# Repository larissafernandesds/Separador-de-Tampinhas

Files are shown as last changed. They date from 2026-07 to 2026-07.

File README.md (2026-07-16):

<h1 align="center">♻️ Separador de Tampinhas ♻️</h1>
<h3 align="center">Grupo 4</h3>

<div align="center">



  





</div>

---

## 📝 Descrição do Projeto  

O **Grupo 4** desenvolveu um **Separador Automático de Tampinhas de Garrafa PET por Cor**. O protótipo possui um **mecanismo alimentador**, no qual o usuário deposita várias tampinhas. Esse mecanismo organiza e **enfileira as tampinhas**, permitindo que elas passem pelo sensor de cores, garantindo uma leitura precisa. Após a leitura, o **Arduino Uno** processa os valores obtidos pelo sensor, identifica a cor da tampinha por meio de perfis previamente calibrados e aciona **servomotores**, responsáveis por direcioná-la ao compartimento correspondente. O sistema também conta com um **display LCD** com módulo I2C, utilizado para fornecer e coletar informações ao usuário durante a calibração.  

---  

## 🎯 Objetivo  

Desenvolver um sistema automatizado capaz de identificar e classificar tampinhas plásticas por cor, aplicando conceitos de sistemas embarcados, eletrônica, automação e programação para tornar o processo de separação mais eficiente e preciso.

---

## 💡 Motivação

A separação de tampinhas plásticas por cor é uma etapa importante do processo de reciclagem, pois aumenta a qualidade do material reciclado e facilita seu reaproveitamento. Quando diferentes cores são misturadas, o material obtido geralmente apresenta menor valor comercial e uma cor escura, dificultando sua reutilização em novos produtos.

Apesar de sua importância, esse processo ainda é realizado manualmente por diversas organizações, cooperativas e iniciativas sociais, tornando a atividade repetitiva, lenta e suscetível a erros. Além disso, a separação manual exige esforço físico constante e limita a quantidade de material que pode ser processada diariamente.

Além do benefício ambiental, a arrecadação de tampinhas possui um importante impacto social. Diversas **ONGs** utilizam a venda do material reciclável para financiar projetos beneficentes e ações de proteção ao meio ambiente. Entre elas destacam-se:

- **Tampinhas que Curam**: iniciativa que arrecada tampinhas plásticas para auxiliar no tratamento de crianças com câncer.
- **Ecopatas**: ONG que arrecada tampinhas plásticas e lacres de alumínio para contribuir com a preservação ambiental e o resgate de animais abandonados.
- **Tampinha do Bem**: projeto voltado à coleta e reciclagem de tampinhas, destinando os recursos obtidos para instituições sociais e ações de proteção animal.
- **Pontos de coleta**: como o instalado no Shopping Vitória (ES), que recebem tampinhas e lacres destinados posteriormente a projetos sociais e ambientais.

---

## 🌱 Impactos e ODSs

ODS

---

## ⚙️ Funcionamento Geral

O funcionamento ocorre em seis etapas principais:

1. O usuário deposita as tampinhas no compartimento superior.

2. O enfileirador organiza as tampinhas e libera apenas uma por vez.

3. A tampinha passa pelo sensor de cores, que realiza a leitura da sua cor.

4. O Arduino compara essa leitura com as cores previamente cadastradas.

5. O sistema identifica a cor correspondente.

6. Os servomotores direcionam a tampinha para o compartimento correto.
   
---

## 🛠️ Arquitetura do Sistema

O sistema foi dividido em dois subsistemas independentes, cada um executado por um Arduino Uno.

### * Enfileirador

O Enfileirador é responsável por organizar mecanicamente as tampinhas depositadas pelo usuário. Seu Arduino controla um servomotor que movimenta o mecanismo responsável por liberar a tampinhas no tubo de leitura.

### * Separador

Seu Arduino realiza a leitura do sensor de cor, identifica automaticamente a cor da tampinha, controla os servomotores responsáveis pelo direcionamento e gerencia toda a interface com o usuário através do display LCD e do encoder rotativo.

---

## 📁 Estrutura do Repositório

```text
Separador-de-Tampinhas/
├── Software/
│   ├── Enfileirador.ino
│   └── Separador.ino
│
├── Hardware/
│   ├── Modelos 3D/
│   └── Imagens/
│      
└── README.md
```
---

## 👶🏻 Como tudo começou...

<div align="center" style="display:flex; gap:20px;">
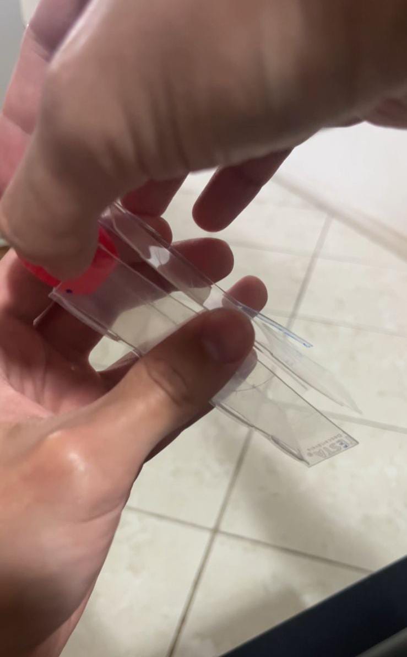
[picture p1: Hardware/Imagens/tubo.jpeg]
  
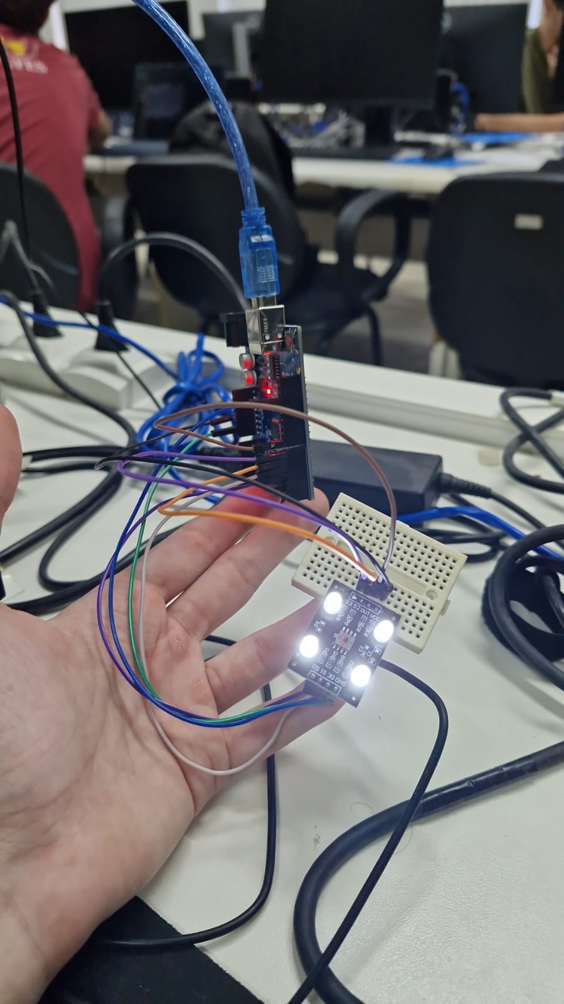
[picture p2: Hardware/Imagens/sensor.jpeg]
  
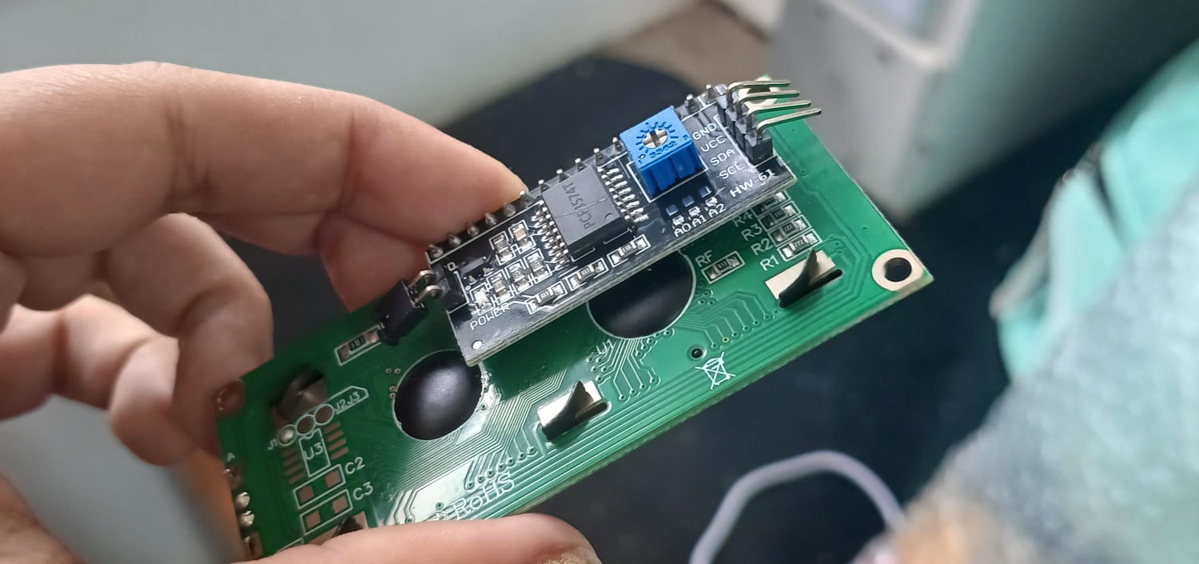
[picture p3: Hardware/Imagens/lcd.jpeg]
  
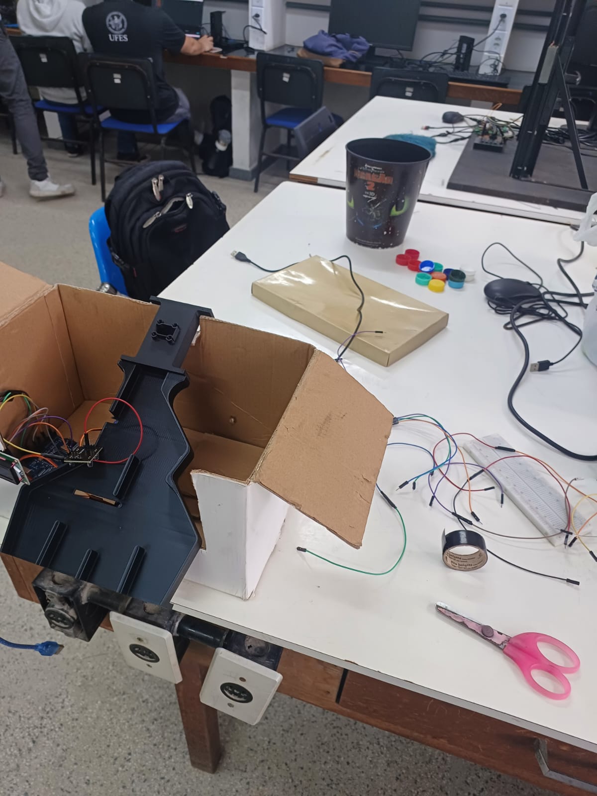
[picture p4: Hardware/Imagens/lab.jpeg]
  
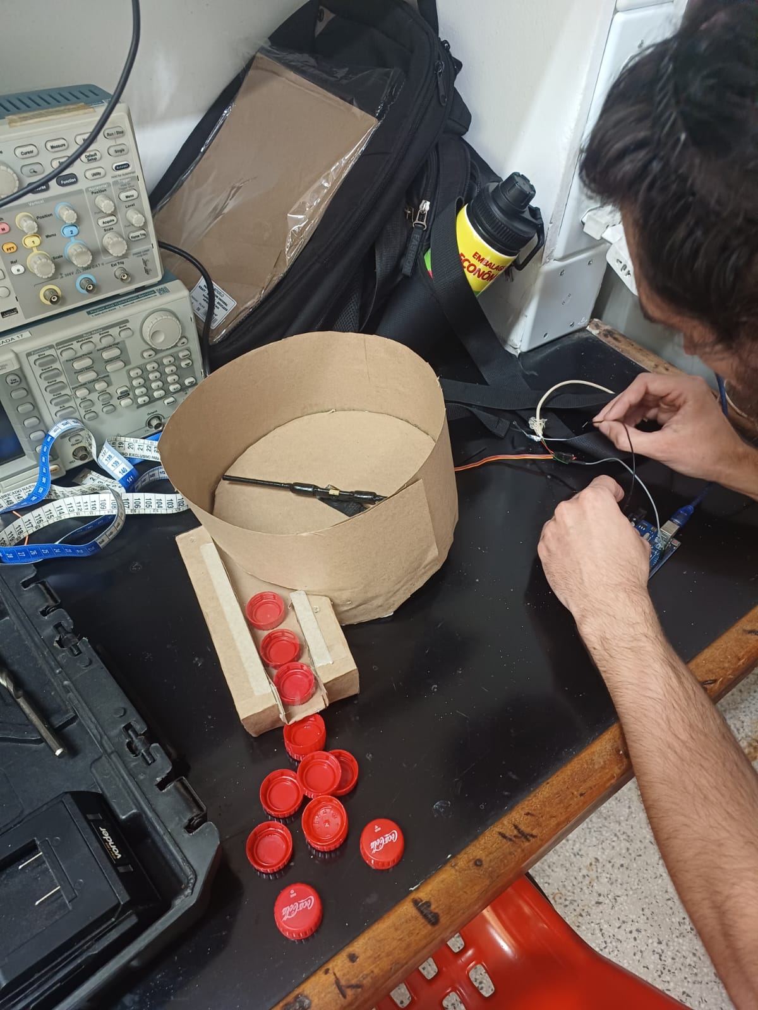
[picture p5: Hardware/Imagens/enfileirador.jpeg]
  
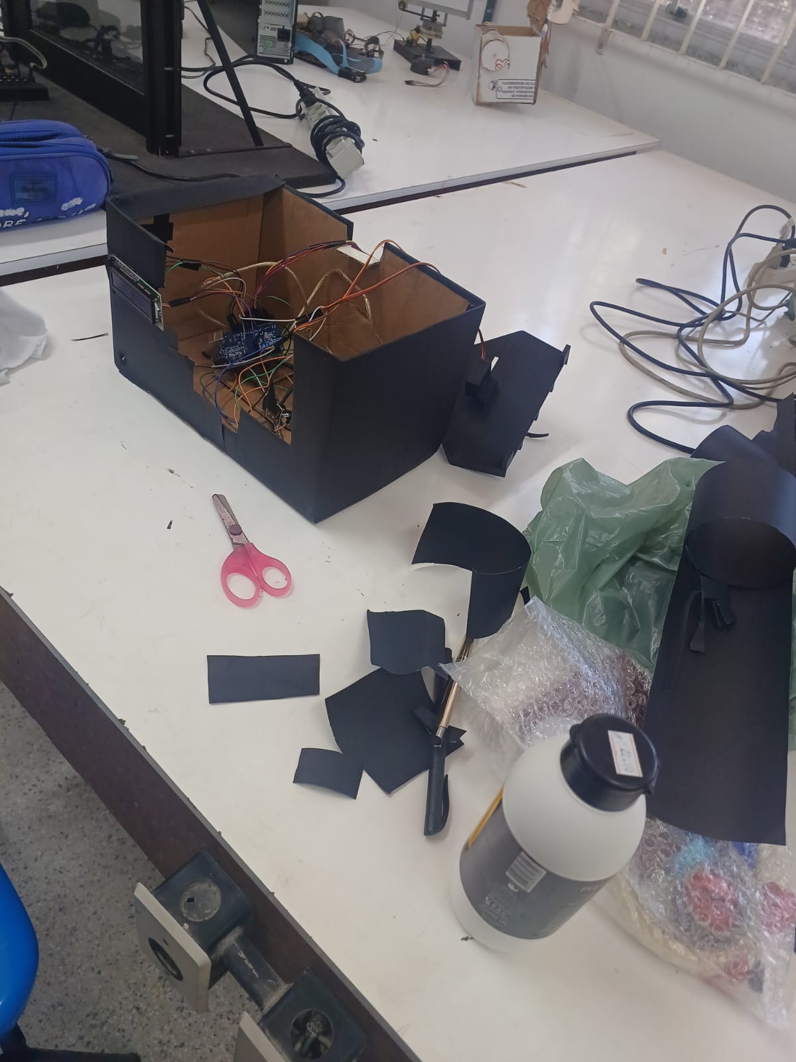
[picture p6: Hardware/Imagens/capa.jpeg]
 
</div>

---

## 📷 Imagens do Projeto Final

<div align="center" style="display:flex; gap:20px;">
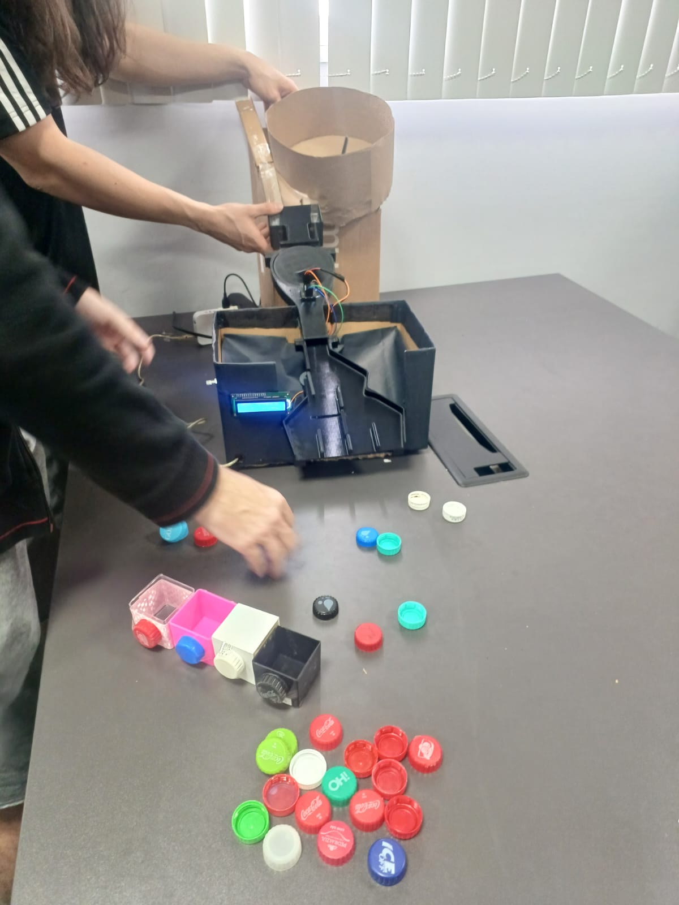
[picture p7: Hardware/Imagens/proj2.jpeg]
 
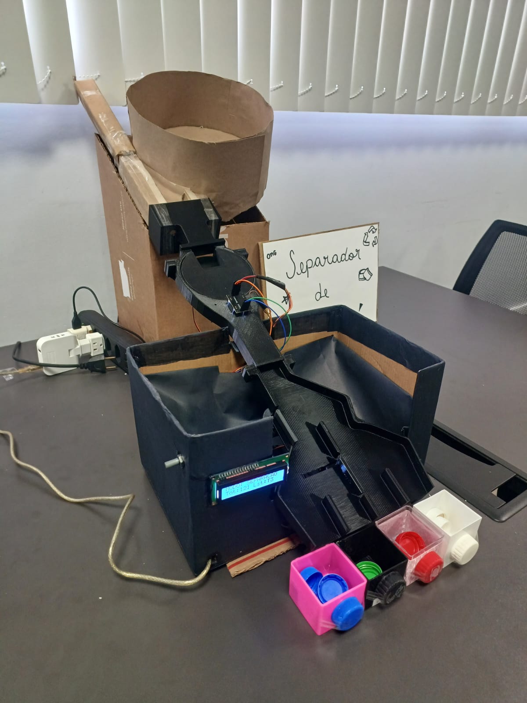
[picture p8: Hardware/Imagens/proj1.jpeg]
 
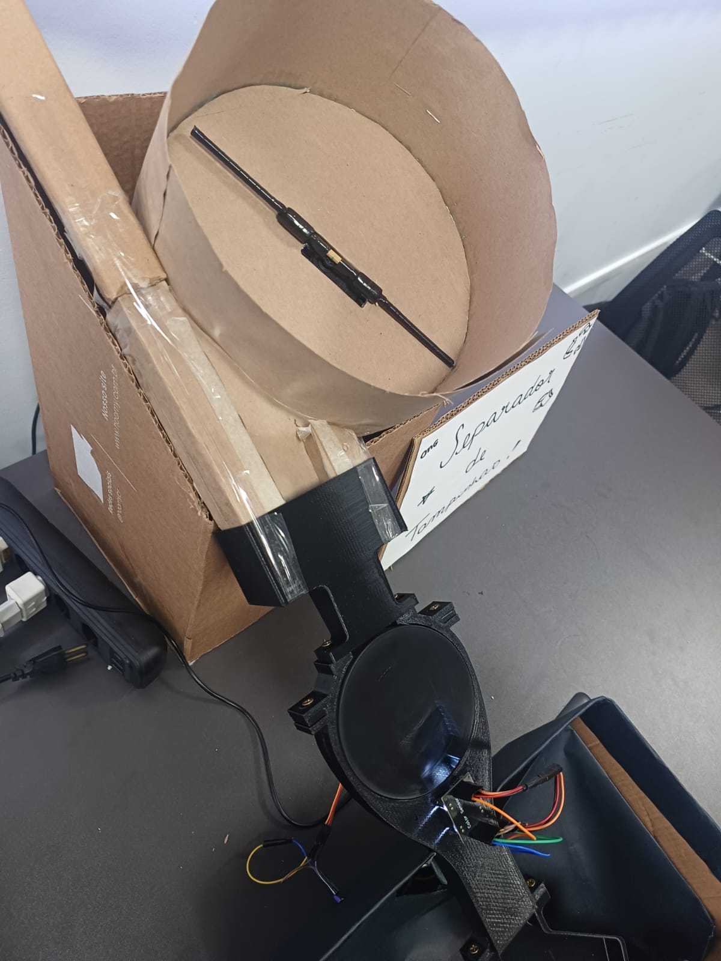
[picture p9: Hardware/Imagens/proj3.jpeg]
 
</div>

---

# 🧠 Software

O software do **Separador** foi desenvolvido utilizando uma máquina de estados composta por dois modos principais.

### Modo Operação

Neste modo o sistema permanece monitorando continuamente o sensor de cor.

Quando uma tampinha entra no tubo de leitura, o Arduino identifica essa alteração, realiza a leitura da cor e determina automaticamente qual compartimento deverá recebê-la.

Após a identificação, os servomotores são acionados e o display LCD atualiza as informações de operação.

### Modo Menu

Ao girar o encoder rotativo, o sistema entra automaticamente no modo de configuração.

Nesse modo o usuário pode:

- calibrar o tubo;
- calibrar cada tampinha;
- apagar toda a EEPROM.

Atualmente o sistema permite calibrar:

- **1 referência do tubo vazio** (utilizada para detectar a queda da tampinha);
- **3 perfis de cores distintos** (Tampa 1, Tampa 2 e Tampa 3).

Após alguns segundos sem interação, o sistema retorna automaticamente ao modo de operação.

---

## 🤖 Código do Separador

As principais funções do codigo do **Separador** (Separador.ino) são:

### setup()

Inicializa todos os periféricos do sistema, incluindo LCD, sensor de cores, encoder rotativo, servomotores e EEPROM.

Também realiza a leitura das calibrações armazenadas.

### loop()

Executa continuamente a máquina de estados do sistema.

Dependendo do modo atual, pode:

- monitorar o sensor de cores;
- controlar o menu;
- atualizar o display LCD;
- gerar os sinais PWM dos servomotores.

### lerRGB()

Seleciona sucessivamente os filtros vermelho, verde e azul do sensor de cor e realiza a leitura da frequência produzida pelo sensor.

### processarQueda()

Executa diversas leituras durante a passagem da tampinha, selecionando automaticamente a leitura mais representativa.

### identificarCor()

Compara a leitura atual com todos os perfis previamente calibrados e determina qual apresenta menor distância.

### moverServos()

Movimenta os servomotores para direcionar a tampinha ao compartimento correspondente.

### executarCalibracao()

Realiza o processo de calibração do tubo ou das tampinhas e armazena os dados na EEPROM.

### executarResetEEPROM()

Apaga todas as calibrações previamente armazenadas.

---

## 💻 Código do Enfileirador

O software do **Enfileirador** tem como única função controlar o servomotor responsável por organizar as tampinhas antes da etapa de identificação. Utilizando a biblioteca `Servo.h`, o programa alterna continuamente o sentido de rotação do servo por meio de comandos `servo.write()`, fazendo com que o mecanismo movimente as tampinhas e libere para o tubo de leitura. 

---

## 👥 Interface com o Usuário

Toda a interação entre o usuário e o sistema ocorre por meio de um display LCD 16×2 com comunicação I2C e de um encoder rotativo.

O display informa o estado atual do equipamento, auxilia durante o processo de calibração e apresenta mensagens de confirmação ao usuário.

Durante o funcionamento podem ser exibidas as seguintes telas.

### Tela de Inicialização

Logo após ligar o equipamento é apresentada uma tela de boas-vindas.

```text
SEPARADOR DE
TAMPINHAS
```
---

### Tela Principal

Após a inicialização, o sistema entra automaticamente no modo de separação.

```text
MODO: SEPARACAO
Tot:15 Lst:T2
```

Nessa tela são exibidas duas informações importantes:

- **Tot**: quantidade total de tampinhas classificadas desde que o sistema foi ligado.
- **Lst**: última tampinha identificada.

Os possíveis valores de **Lst** são:

| Valor | Significado |
|---|---|
| T1 | Última tampinha identificada foi a Tampa 1 |
| T2 | Última tampinha identificada foi a Tampa 2 |
| T3 | Última tampinha identificada foi a Tampa 3 |
| Desc | Cor desconhecida (não corresponde a nenhuma cor calibrada) |
| Nenhuma | Nenhuma tampinha foi identificada desde a inicialização |

---

### Menu de Configuração

Ao girar o encoder rotativo o sistema entra automaticamente no menu.

```text
MENU:
TUBO
```

ou

```text
MENU:
Tampa 1
```

ou

```text
MENU:
Tampa 2
```

ou

```text
MENU:
Tampa 3
```

ou

```text
MENU:
RESET EEPROM
```

Quando um perfil já foi calibrado, o display apresenta:

```text
MENU:
Tampa 2 [OK]
```

A indicação **[OK]** significa que aquela calibração já está armazenada na EEPROM.

---

### Calibração

Durante a calibração do tubo:

```text
CALIBRANDO:
TUBO
```

Em seguida:

```text
Lendo Tubo...
```

O sistema realiza a leitura da referência do tubo vazio.

---

Durante a calibração das tampinhas:

```text
CALIBRANDO:
Tampa 1
```

Depois solicita cada uma das cinco passagens da tampinha.

```text
Solte tampa 1
Aguardando...
```

Após detectar corretamente a passagem:

```text
Capturado! OK.
```

Esse processo é repetido cinco vezes.

Ao final, o sistema calcula automaticamente a média das leituras obtidas e armazena o perfil na EEPROM.

---

### Salvamento

Após concluir a calibração é apresentada a mensagem:

```text
Salvo na EEPROM!
```

Isso indica que a calibração foi armazenada permanentemente na memória EEPROM.

---

### Reset da EEPROM

Quando o usuário seleciona a opção de apagar todas as calibrações, o display informa:

```text
LIMPANDO EEPROM...
```

Após concluir a operação:

```text
EEPROM Resetada!
```

Todas as referências de cores são apagadas e uma nova calibração poderá ser realizada.

---

# 🔌 Hardware

## 🪛 Materiais

**Microcontroladores**
- 1 Arduino Uno (Enfileirador)
- 1 Arduino Uno (Separador)
  
**Sensores**
- 1 Sensor de cores TCS230/TCS3200
  
**Atuadores**
- 3 Servomotores SG90 9g
- 1 Servomotor GOLD AMS5811G
  
**Interface**
- 1 Display LCD 16×2 com módulo I2C integrado
- 1 Encoder Decoder Rotacional KY-040
  
**Alimentação**
- Fontes externas 5V etc...
  
**Demais componentes**
- Jumpers
- Estruturas impressas em 3D
- Placa perfurada de fenolite
- Tampinhas de garrafa PET
- Papelão
- 4 mini compartimentos
- Materiais como: cartolina, papel kraft, cola, durex, palito etc..

---

## 🔌 Ligações

São apresentados abaixo os principais sinais utilizados pelo módulo **Separador**.

| Arduino | Dispositivo |
|---|---|
| D3 | Servo 1 |
| D11 | Servo 2 |
| D13 | Servo 3 |
| D5 | OUT do sensor de cor |
| D4 | S0 do sensor de cor |
| D9 | S1 do sensor de cor |
| D6 | S2 do sensor de cor |
| D7 | S3 do sensor de cor |
| D2 | Encoder CLK |
| D8 | Encoder DT |
| D10 | Encoder SW |
| GND | GND Encoder |
| VCC | VCC Encoder |
| SDA | SDA LCD I2C |
| SCL | SCL LCD I2C |
| GND | GND LCD I2C |
| VCC | VCC LCD I2C |
| GND | GND Fonte Externa |

Demais conexões do circuito: distribuição da alimentação por meio de uma **placa perfurada de fenolite**, a **fonte externa de 5V** utilizada para alimentar os servomotores e o Arduino do Enfileirador, responsável pelo acionamento de um servomotor dedicado etc.

---

## 🖨 Modelos 3D

**Todas** as peças mecânicas do projeto foram modeladas no **Autodesk Inventor**.

Os modelos encontram-se na pasta `Hardware/Modelos 3D/` e são disponibilizados no formto .stl.

---

## 🌈 Sensor de Cor

O sistema utiliza o sensor de cores **TCS230/TCS3200**, responsável por realizar a identificação das tampinhas plásticas através da análise da luz refletida pela superfície de cada material.

Ele é um sensor óptico composto por uma matriz de fotodiodos e um conversor de corrente para frequência. Ele possui filtros internos que permitem selecionar a leitura das componentes de cor **vermelho (R), verde (G) e azul (B)**, além de uma leitura sem filtro.

O funcionamento do sensor ocorre da seguinte forma: uma fonte de luz interna ilumina o objeto posicionado à frente do sensor. A luz refletida pela tampinha atinge os fotodiodos, que geram uma corrente elétrica proporcional à intensidade luminosa recebida. Essa corrente é convertida internamente pelo circuito do sensor em um sinal digital de frequência.

Dessa forma, quanto maior a intensidade da cor selecionada, maior será a frequência do sinal de **saída (OUT)** gerado pelo sensor.

O Arduino não recebe diretamente valores de vermelho, verde e azul. Em vez disso, ele mede a frequência produzida pelo sensor para cada filtro de cor e utiliza esses valores para calcular uma representação RGB da tampinha analisada.

---

## 📋 Pré-requisitos

- Arduino IDE 2.x (ou superior);
- Driver da placa Arduino Uno (caso necessário);
- Bibliotecas da Arduino IDE:
  - Servo
  - EEPROM
  - Wire
  - LiquidCrystal_I2C
  - FreqCount
- Hardware descrito anteriormente.

---

## ▶️ Instruções de Execução

1. Monte os circuitos.
2. Grave o programa `Enfileirador.ino` no Arduino responsável pelo enfileiramento.
3. Grave o programa `Separador.ino` no Arduino responsável pela classificação.
4. Ligue a alimentação do sistema.
5. Realize a calibração do tubo pelo menu.
6. Calibre cada uma das tampinhas.
7. Inicie a operação automática do equipamento.

---

## 🚀 Evolução em Relação ao Pitch

Os objetivos propostos no pitch foram alcançados com sucesso. Além disso, durante o desenvolvimento do projeto foi possível ampliar o escopo inicialmente planejado.

Originalmente, o sistema previa apenas a identificação e separação das tampinhas por cor. No decorrer do desenvolvimento, observou-se a necessidade de organizar a alimentação das tampinhas para garantir mais agilidade. Como resultado, foi desenvolvido um segundo subsistema, denominado **Enfileirador de Tampinhas**, composto por um Arduino dedicado e um servomotor responsável por organizar e liberar as tampinhas.

---

## ⏳ Estado Atual do Projeto

✔️ Completo

**Progresso estimado: ~100%**

---

## 🎥 Vídeo Pitch

Um pitch do projeto está disponível no link abaixo:

🔗 [Clique aqui para assistir ao vídeo do projeto](https://www.youtube.com/watch?v=MaOEnb36ciA)

---

## 🏁 Conclusão

O projeto permitiu a aplicação prática de conceitos de eletrônica, programação embarcada e automação, proporcionando aprendizado técnico, trabalho em equipe e desenvolvimento de uma solução tecnológica integrada.

---

## 👩‍💻 Colaboradores

| <br><sub>André Silvares</sub> | <br><sub>Daniel Moulin</sub> |<br><sub>Larissa Fernandes</sub> | <br><sub>Rafael Santiago</sub> |
| :---: | :---: | :---: | :---: |
---

## 📌 Observação

O projeto possui caráter **acadêmico e experimental**, sendo desenvolvido para a
disciplina **Projeto Integrado de Computação II** da UFES, com foco na integração entre
software, hardware e sociedade.

---

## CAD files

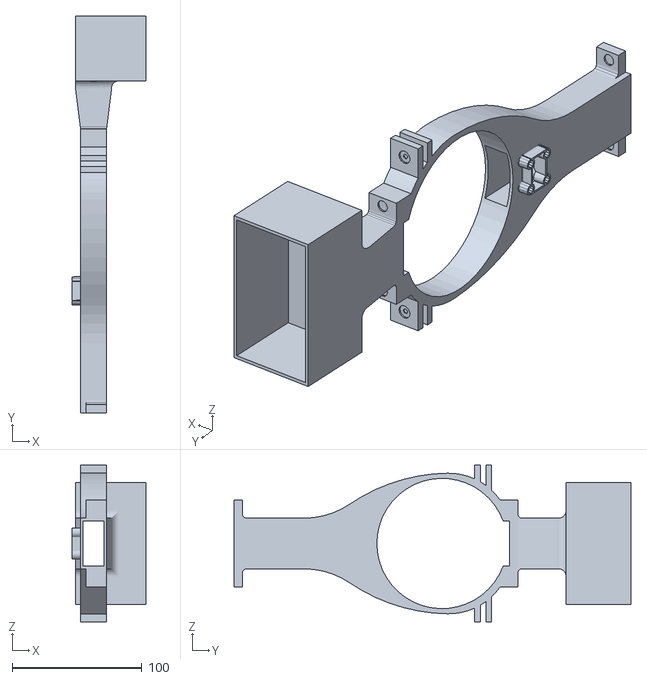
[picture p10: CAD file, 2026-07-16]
Hardware/Modelos 3D/interface.stl
56.8 x 305.6 x 120.5

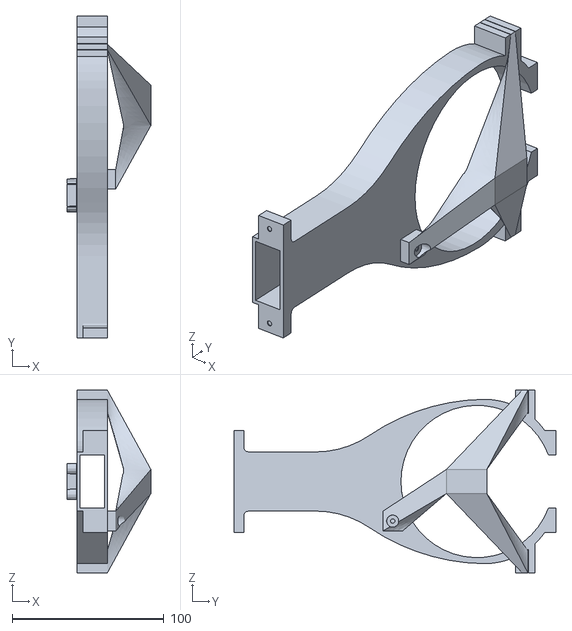
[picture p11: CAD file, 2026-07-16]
Hardware/Modelos 3D/FeederSup.stl
55.2 x 212.1 x 120.5

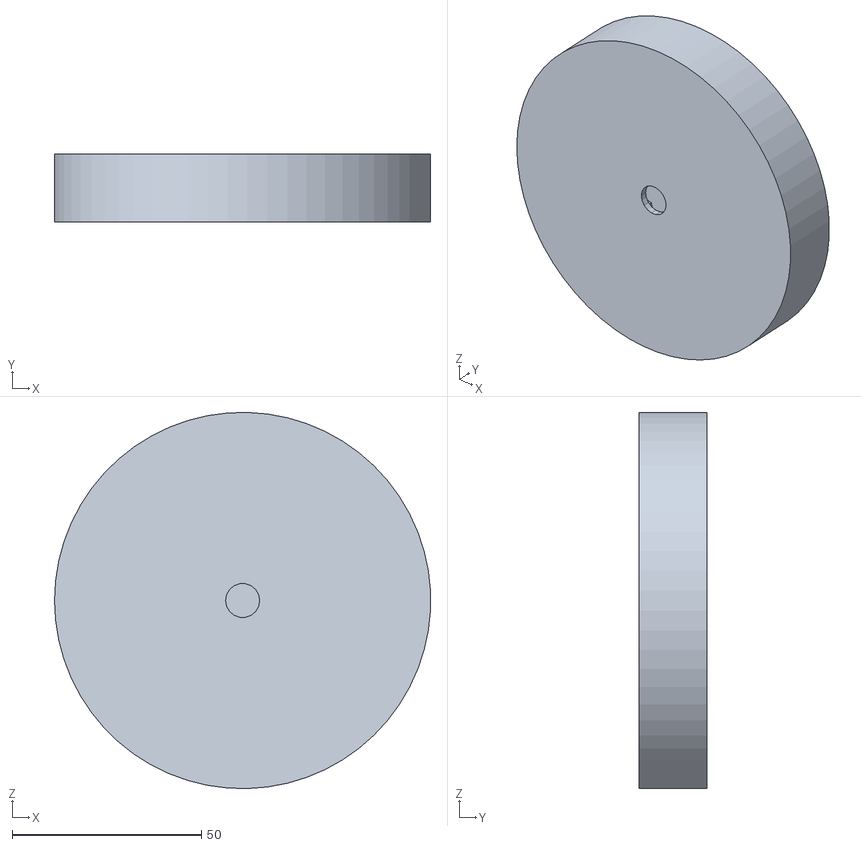
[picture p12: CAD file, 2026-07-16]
Hardware/Modelos 3D/FeederWheel.stl
99.2 x 18.0 x 99.2

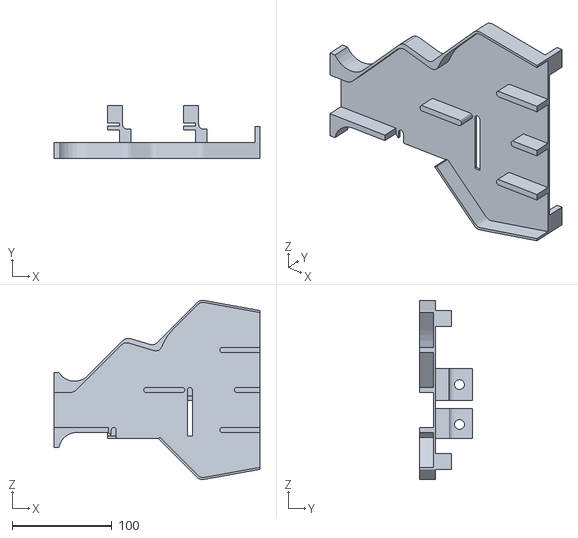
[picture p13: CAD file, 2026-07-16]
Hardware/Modelos 3D/GuideAct.stl
206.2 x 53.4 x 179.5

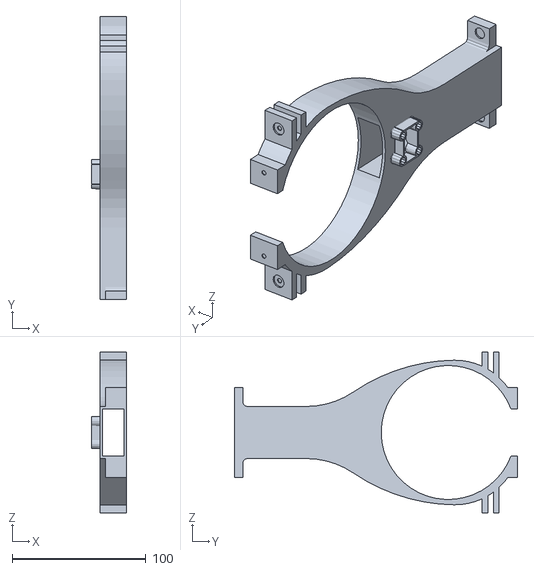
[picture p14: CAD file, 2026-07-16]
Hardware/Modelos 3D/SensorSegment.stl
26.5 x 212.1 x 120.5

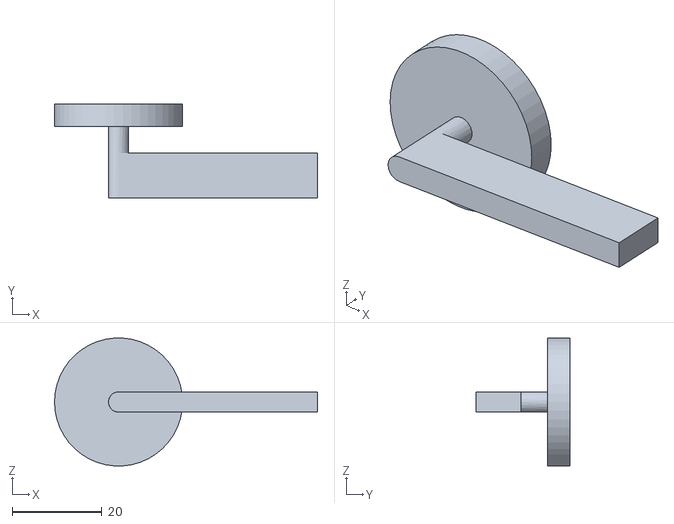
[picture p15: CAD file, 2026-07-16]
Hardware/Modelos 3D/HandleAct.stl
58.5 x 20.9 x 28.4

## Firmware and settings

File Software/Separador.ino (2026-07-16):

#include <FreqCount.h>
#include <EEPROM.h>
#include <Wire.h>
#include <LiquidCrystal_I2C.h>

// Definições de Pinos do Sensor e Servos
#define S0 4
#define S1 9
#define S2 6
#define S3 7
#define OUT 5 
#define PINO_SERVO1 3 
#define PINO_SERVO2 11
#define PINO_SERVO3 13

// Definições do Encoder Rotativo
#define ENC_CLK 2  // Pino com suporte a interrupção no Uno/Nano
#define ENC_DT  8
#define ENC_SW  10

// Inicialização do LCD
LiquidCrystal_I2C lcd(0x27, 16, 2);

// Máquina de Estados do Sistema
enum EstadoSistema { MODO_OPERACAO, MODO_MENU };
EstadoSistema estadoAtual = MODO_OPERACAO;

// Variáveis de Controle do Encoder
volatile int posicaoMenu = 0;
volatile bool encoderMovido = false;
int ultimaPosicaoMenu = -1;
unsigned long tempoUltimoBotao = 0;
unsigned long tempoUltimaInteracaoMenu = 0;
const unsigned long TIMEOUT_MENU = 8000; // 8 segundos de inatividade voltam para a operação

const unsigned long TEMPO_DEBOUNCE = 1000; 
unsigned long ultimaIdentificacao = 0;

// Variáveis dos Servos e Timers
int larguraPulso1 = 1570;   
unsigned long ultimoPulso = 0;
unsigned long tempoResetServo = 0;
int larguraPulso2 = 1570;   
unsigned long tempoResetServo2 = 0;
int larguraPulso3 = 530;
unsigned long tempoMoverServo3 = 0;
bool direcaoServo3 = true;
unsigned long intervaloServo3 = (estadoAtual == MODO_MENU) ? 3000 : 1000;

// Estrutura do Perfil de Cor
struct ColorProfile {
  long rRaw, gRaw, bRaw;
  float rn, gn, bn;
  bool configurada;
};

// Modificado para 5 posições (Tubo + 3 Tampas + Reset)
ColorProfile alvos[4]; // Apenas os 4 primeiros guardam cores
const char* nomes[] = {"TUBO", "Tampa 1", "Tampa 2", "Tampa 3", "RESET EEPROM"};
int threshold = 20; 

// Contadores de Tampas para o Modo Operação
int contagemTampas = 0;
String ultimaTampaDetectada = "Nenhuma";

// ISR para leitura rápida do Encoder
void lerEncoder() {
  if (digitalRead(ENC_CLK) == digitalRead(ENC_DT)) {
    posicaoMenu++;
    if (posicaoMenu > 4) posicaoMenu = 0; // Limite ajustado para 4 (5 itens)
  } else {
    posicaoMenu--;
    if (posicaoMenu < 0) posicaoMenu = 4; 
  }
  encoderMovido = true;
}

void setup() {
  // Inicialização do LCD
  lcd.init();
  lcd.backlight();
  lcd.setCursor(0, 0);
  lcd.print("  SEPARADOR DE   ");
  lcd.setCursor(0, 1);
  lcd.print("    TAMPINHAS    ");
  delay(1500);

  // Setup Servos e Sensor
  pinMode(PINO_SERVO1, OUTPUT);
  pinMode(PINO_SERVO2, OUTPUT);
  pinMode(PINO_SERVO3, OUTPUT);
  pinMode(S0, OUTPUT); pinMode(S1, OUTPUT);
  pinMode(S2, OUTPUT); pinMode(S3, OUTPUT);
  digitalWrite(S0, HIGH); digitalWrite(S1, HIGH);
  FreqCount.begin(3); 

  // Setup Encoder
  pinMode(ENC_CLK, INPUT);
  pinMode(ENC_DT, INPUT);
  pinMode(ENC_SW, INPUT_PULLUP);
  attachInterrupt(digitalPinToInterrupt(ENC_CLK), lerEncoder, CHANGE);

  // Carrega dados da EEPROM
  for(int i=0; i<4; i++) {
    EEPROM.get(i * sizeof(ColorProfile), alvos[i]);
    if(isnan(alvos[i].rn) || !alvos[i].configurada) {
      alvos[i].configurada = false;
    }
  }
  
  lcd.clear();
  atualizarTelaOperacao();
}

void loop() {
  
  // Captura segura das flags da ISR (Evita Race Conditions)
  noInterrupts();
  bool mudouEncoder = encoderMovido;
  int menuAtual = posicaoMenu;
  encoderMovido = false;
  interrupts();

  // Transição de Estado: Se mexer no encoder, vai para o Menu
  if (mudouEncoder && estadoAtual == MODO_OPERACAO) {
    estadoAtual = MODO_MENU;
    ultimaPosicaoMenu = -1; // Força atualização do LCD
    tempoUltimaInteracaoMenu = millis();
  }

  // LÓGICA DE CADA ESTADO
  if (estadoAtual == MODO_MENU) {
    // Gerenciamento do Menu no LCD
    if (menuAtual != ultimaPosicaoMenu || mudouEncoder) {
      tempoUltimaInteracaoMenu = millis();
      ultimaPosicaoMenu = menuAtual;
      
      lcd.setCursor(0, 0);
      lcd.print("MENU:           ");
      lcd.setCursor(0, 1);
      lcd.print("                "); // Limpa linha
      lcd.setCursor(0, 1);
      lcd.print(nomes[menuAtual]);
      
      // Se for um índice de cor e estiver configurado, mostra [OK]
      if (menuAtual < 4 && alvos[menuAtual].configurada) {
        lcd.print(" [OK]");
      }
    }

    // Timeout do Menu (Volta para operação se ficar inativo)
    if (millis() - tempoUltimaInteracaoMenu > TIMEOUT_MENU) {
      estadoAtual = MODO_OPERACAO;
      atualizarTelaOperacao();
    }

    // Clique do Botão no Modo Menu
    if (digitalRead(ENC_SW) == LOW) {
      if (millis() - tempoUltimoBotao > 300) { // Debounce do botão
        if (menuAtual == 4) {
          executarResetEEPROM();
        } else {
          executarCalibracao(menuAtual);
        }
        tempoUltimoBotao = millis();
        estadoAtual = MODO_OPERACAO; // Volta para operação após calibrar/resetar
        atualizarTelaOperacao();
      }
    }

  } else {
    // MODO_OPERACAO: Executa a leitura e separação ativamente
    long r, g, b;
    lerRGB(r, g, b);

    unsigned long tempoAtual = millis(); // Captura o tempo atual para o debounce da queda

    // O gatilho agora só dispara se o threshold for atingido E se passou o TEMPO_DEBOUNCE
    if (alvos[0].configurada && 
        (tempoAtual - ultimaIdentificacao >= TEMPO_DEBOUNCE) && // <- Trava de tempo adicionada aqui
        (abs(r - alvos[0].rRaw) > threshold || 
         abs(g - alvos[0].gRaw) > threshold || 
         abs(b - alvos[0].bRaw) > threshold)) {
      
      ultimaIdentificacao = tempoAtual; // Bloqueia novas leituras falsas
      processarQueda();
    }
  }


  if (millis() >= 30000) { 
    if (millis() - tempoMoverServo3 >= intervaloServo3) {
      tempoMoverServo3 = millis();
      if (direcaoServo3) {
        larguraPulso3 = 2470; // 180 graus
      } else {
        larguraPulso3 = 530;  // 0 graus
      }
      direcaoServo3 = !direcaoServo3;
    }
  } else {
    // Garante que nos primeiros 10 segundos ele permaneça estrito em 530
    larguraPulso3 = 530;
    tempoMoverServo3 = millis(); // Mantém o timer zerado para começar a contar o 1s após o timeout
  }

  // PWM MANUAL DOS SERVOS (Permanece rodando em paralelo em ambos os estados)
  atualizarServosPWM();

  // Gerenciadores de retorno ao neutro
  if (tempoResetServo > 0 && millis() > tempoResetServo) {
    larguraPulso1 = 1570; 
    tempoResetServo = 0;
  }
  if (tempoResetServo2 > 0 && millis() > tempoResetServo2) {
    larguraPulso2 = 1570;
    tempoResetServo2 = 0;
  }
}

// ================== NOVO: PWM extraído para função própria ==================
// Gera o pulso dos 3 servos com base nas variáveis globais larguraPulsoX.
// Precisa ser chamada com frequência (a cada ~20ms) mesmo dentro de trechos
// bloqueantes (delay/while de calibração), senão o servo 3 "congela" na
// última posição em vez de ir para 530 como esperado.
void atualizarServosPWM() {
  if (micros() - ultimoPulso >= 20000) { 
    digitalWrite(PINO_SERVO1, HIGH);
    delayMicroseconds(larguraPulso1);
    digitalWrite(PINO_SERVO1, LOW);

    digitalWrite(PINO_SERVO2, HIGH);
    delayMicroseconds(larguraPulso2);
    digitalWrite(PINO_SERVO2, LOW);

    digitalWrite(PINO_SERVO3, HIGH);
    delayMicroseconds(larguraPulso3);
    digitalWrite(PINO_SERVO3, LOW);
    
    ultimoPulso = micros();
  }
}

// Substituto do delay() que mantém os servos recebendo pulso durante a espera.
// Use isso no lugar de delay() dentro de qualquer função bloqueante
// (calibração, reset da EEPROM, etc).
void delayComServo(unsigned long ms) {
  unsigned long inicio = millis();
  while (millis() - inicio < ms) {
    atualizarServosPWM();
  }
}
// ==============================================================================

void atualizarTelaOperacao() {
  lcd.clear();
  lcd.setCursor(0, 0);
  lcd.print("MODO: SEPARACAO");
  lcd.setCursor(0, 1);
  lcd.print("Tot:");
  lcd.print(contagemTampas);
  lcd.print(" Lst:");
  lcd.print(ultimaTampaDetectada);
}

void lerRGB(long &r, long &g, long &b) {
  digitalWrite(S2, LOW);  digitalWrite(S3, LOW);  r = getFastFreq();
  digitalWrite(S2, HIGH); digitalWrite(S3, HIGH); g = getFastFreq();
  digitalWrite(S2, LOW);  digitalWrite(S3, HIGH); b = getFastFreq();
}

unsigned long getFastFreq() {
  while (FreqCount.available()) FreqCount.read(); 
  while (!FreqCount.available());                 
  return FreqCount.read();
}

void processarQueda() {
  float bRn, bGn, bBn, maxDiff = -1.0;
  unsigned long start = millis();

  while (millis() - start < 18) {
    long r, g, b;
    lerRGB(r, g, b);
    float total = r + g + b + 1;
    float rn = r/total, gn = g/total, bn = b/total;
    float diff = abs(rn - alvos[0].rn) + abs(gn - alvos[0].gn) + abs(bn - alvos[0].bn);
    
    if (diff > maxDiff) {
      maxDiff = diff; bRn = rn; bGn = gn; bBn = bn;
    }
  }

  if (maxDiff > 0.05) identificarCor(bRn, bGn, bBn);
}

void identificarCor(float rn, float gn, float bn) {
  int melhorMatch = -1;
  float menorDist = 999.0;

  for (int i = 1; i < 4; i++) {
    if (!alvos[i].configurada) continue;

    float dR = rn - alvos[i].rn;
    float dG = gn - alvos[i].gn;
    float dB = bn - alvos[i].bn;
    float dist = sqrt(dR*dR + dG*dG + dB*dB);

    if (dist < menorDist) {
      menorDist = dist; melhorMatch = i;
    }
  }

  if (melhorMatch != -1 && menorDist < 0.09) {
    moverServos(melhorMatch);
    ultimaTampaDetectada = "T" + String(melhorMatch);
    contagemTampas++;
  } else {
    moverServos(0); 
    ultimaTampaDetectada = "Desc";
  }
  
  // Atualiza rapidamente o visor após a detecção
  atualizarTelaOperacao();
}

void moverServos(int tipo) {
  switch (tipo) {
    case 1: larguraPulso1 = 2050; larguraPulso2 = 2100; break; 
    case 2: larguraPulso1 = 2050;  larguraPulso2 = 1570;  break; 
    case 3: larguraPulso1 = 1570; larguraPulso2 = 950; break; 
    default: larguraPulso1 = 1570; larguraPulso2 = 1570; break; 
  }
  
  if (tipo != 0) {
    tempoResetServo = millis() + 800;
    tempoResetServo2 = millis() + 1000;
  }
}

void executarResetEEPROM() {
  lcd.clear();
  lcd.setCursor(0, 0);
  lcd.print("LIMPANDO EEPROM...");
  
  // Desconfigura na RAM e limpa os blocos correspondentes na EEPROM
  for(int i = 0; i < 4; i++) {
    alvos[i].configurada = false;
    alvos[i].rn = 0.0; alvos[i].gn = 0.0; alvos[i].bn = 0.0;
    alvos[i].rRaw = 0; alvos[i].gRaw = 0; alvos[i].bRaw = 0;
    EEPROM.put(i * sizeof(ColorProfile), alvos[i]);
  }
  
  delayComServo(1500);
  lcd.clear();
  lcd.setCursor(0, 0);
  lcd.print("EEPROM Resetada!");
  delayComServo(1500);
}

void executarCalibracao(int idx) {
  lcd.clear();
  lcd.setCursor(0, 0);
  lcd.print("CALIBRANDO:");
  lcd.setCursor(0, 1);
  lcd.print(nomes[idx]);
  delayComServo(1000);
  
  if (idx == 0) { // CALIBRAÇÃO DO TUBO
    lcd.clear();
    lcd.setCursor(0, 0);
    lcd.print("Lendo Tubo...");
    delayComServo(1000);
    long r, g, b; lerRGB(r, g, b);
    alvos[0].rRaw = r; alvos[0].gRaw = g; alvos[0].bRaw = b;
    float total = r + g + b + 1;
    alvos[0].rn = r/total; alvos[0].gn = g/total; alvos[0].bn = b/total;
    alvos[0].configurada = true;
  } 
  else { // CALIBRAÇÃO DAS TAMPAS (MÉDIA DE 5 QUEDAS)
    // Garante que o servo 3 vá para a posição de repouso (0 graus) durante a calibração
    larguraPulso3 = 530; 
    direcaoServo3 = true;
    
    float somaRn = 0, somaGn = 0, somaBn = 0;
    int coletas = 0;

    while (coletas < 5) {
      lcd.clear();
      lcd.setCursor(0, 0);
      lcd.print("Solte tampa "); lcd.print(coletas + 1);
      lcd.setCursor(0, 1);
      lcd.print("Aguardando...   ");
      
      bool detectou = false;
      while (!detectou) {
        atualizarServosPWM(); // <- mantém o servo 3 travado em 530 enquanto espera a tampa
        long r, g, b; lerRGB(r, g, b);
        if (abs(r - alvos[0].rRaw) > threshold || abs(g - alvos[0].gRaw) > threshold || abs(b - alvos[0].bRaw) > threshold) {
          
          float pRn, pGn, pBn, pMax = -1.0;
          unsigned long s = millis();
          while(millis() - s < 50) { 
            atualizarServosPWM(); // <- idem durante a janela de captura da queda
            long rL, gL, bL; lerRGB(rL, gL, bL);
            float t = rL + gL + bL + 1;
            float rn = rL/t, gn = gL/t, bn = bL/t;
            float diff = abs(rn - alvos[0].rn) + abs(gn - alvos[0].gn) + abs(bn - alvos[0].bn);
            if(diff > pMax) { pMax = diff; pRn = rn; pGn = gn; pBn = bn; }
          }
          
          somaRn += pRn; somaGn += pGn; somaBn += pBn;
          coletas++;
          detectou = true;
          
          lcd.setCursor(0, 1);
          lcd.print("Capturado! OK.  ");
          delayComServo(1200);
        }
      }
    }

    alvos[idx].rn = somaRn / 5.0;
    alvos[idx].gn = somaGn / 5.0;
    alvos[idx].bn = somaBn / 5.0;
    alvos[idx].configurada = true;
  }

  if (alvos[idx].configurada) {
    EEPROM.put(idx * sizeof(ColorProfile), alvos[idx]);
    lcd.clear();
    lcd.setCursor(0, 0);
    lcd.print("Salvo na EEPROM!");
    delayComServo(1500);
  }
}
